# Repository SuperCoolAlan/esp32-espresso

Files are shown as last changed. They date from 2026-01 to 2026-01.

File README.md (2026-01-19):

# ESP32 Espresso Machine Controller

An open-source PID temperature controller for espresso machines, featuring WiFi connectivity and precise temperature control.

## Project Structure

```
esp32-espresso/
├── pid-controller/     # PCB design (atopile)
│   ├── main.ato        # Main circuit definition
│   ├── components/     # Custom component definitions
│   └── build/          # Generated manufacturing files
└── pyproject.toml      # Python dependencies
```

## Hardware

The controller board is designed in [atopile](https://atopile.io) and manufactured via JLCPCB.

### Features

- **ESP32-S3** microcontroller with WiFi/BLE
- **On-board AC-DC converter** (100-240V AC → 5V DC) - direct mains power
- **USB Type-C** for programming/debugging (also provides backup power)
- **MAX31855** K-type thermocouple interface for precise temperature measurement
- **External SSR control** for heater switching (supports 25A panel-mount SSRs)
- **Pressure sensor input** with 5V→3.3V level shifting
- **Status LEDs** for system state indication

See [pid-controller/README.md](pid-controller/README.md) for detailed board documentation.

## Building the PCB

```bash
# Install dependencies
uv sync

# Build the PCB
cd pid-controller
ato build
```

Manufacturing files will be generated in `pid-controller/build/default/`.

## License

See individual component licenses in their respective directories.

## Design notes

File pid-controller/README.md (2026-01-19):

# ESP32-S3 PID Controller for Espresso Machine

A PID temperature controller board designed for the Rancilio Silvia espresso machine, built with [atopile](https://atopile.io).

## TODO

- [ ] **Fuse on AC input** - protects against shorts/overcurrent
- [ ] **MOV/TVS on AC input** - surge protection from mains spikes
- [ ] **TVS diodes on USB D+/D-** - ESD protection (e.g., USBLC6-2)
- [ ] **TVS on thermocouple inputs** - TC wires run outside enclosure
- [ ] **Power LED** - indicates board is powered
- [ ] **Reset button** - useful for development
- [ ] **Mounting holes** - for securing PCB in enclosure
- [ ] **Test points** - on key signals for debugging
- [ ] **Fiducials** - alignment markers for pick and place assembly

## Board Overview

This board provides closed-loop temperature control for an espresso machine boiler using a K-type thermocouple and an external solid-state relay.

### Major Components

| Component | Part Number | Description |
|---|---|---|
| MCU | ESP32-S3-WROOM-1-N8 | WiFi/BLE module, 8MB flash |
| AC-DC Converter | HLK-PM01 | 100-240V AC → 5V DC @ 600mA (3W) |
| Thermocouple IC | MAX31855KASA | K-type thermocouple-to-digital converter |
| Voltage Regulator | AMS1117-3.3 | 3.3V LDO (from 5V) |
| SSR Driver | BC817-40 | NPN transistor for external SSR control |
| Power Diode | SS14 | Schottky diode for USB/AC power OR-ing |

### Connectors / Terminals

| Connector | Pins | Function |
|---|---|---|
| J_AC | 2 | AC mains input (Line, Neutral) |
| J_USB | USB-C | Programming/debugging + backup 5V power |
| J_TC | 2 | K-type thermocouple input (TC+, TC-) |
| J_SSR | 2 | External SSR control output (SSR+, SSR-) |
| J_PRESSURE | 3 | Pressure sensor input (+5V, Signal, GND) |

### Status LEDs

| LED | Color | Function |
|-----|---|---|
| LED_OK | Green | System running / OK |
| LED_HEAT | Orange | Heating element active |
| LED_ERR | Red | Error condition |

All LEDs are active-low (accent driven by GPIO sinking current).

## Pin Assignments

### ESP32-S3 GPIO Usage

| GPIO | Function |
|---|---|
| IO1 | Pressure sensor ADC input |
| IO4 | SSR control output |
| IO5 | Green LED (OK) |
| IO6 | Orange LED (Heating) |
| IO7 | Red LED (Error) |
| IO10 | SPI CS (MAX31855) |
| IO11 | SPI MOSI (unused) |
| IO12 | SPI CLK (MAX31855) |
| IO13 | SPI MISO (MAX31855) |
| IO19 | USB D- |
| IO20 | USB D+ |

## External SSR Wiring

This board outputs a control signal for an external panel-mount SSR (e.g., Fotek SSR-25DA or similar 25A SSR). The external SSR provides better heat dissipation for high-power loads.

```
Board J_SSR          External SSR (25A)         Heater
┌─────────┐          ┌─────────────┐           ┌──────┐
│ Pin 1 ──┼──────────┤ Input +     │           │      │
│ (SSR+)  │          │ (3-32VDC)   │           │      │
│         │          │             ├───────────┤ Load │
│ Pin 2 ──┼──────────┤ Input -     │    AC     │      │
│ (SSR-)  │          │             ├───────────┤      │
└─────────┘          └─────────────┘           └──────┘
```

## Circuit Features

- **AC-DC Power**: On-board HLK-PM01 isolated converter (100-240V AC → 5V DC)
- **USB Type-C**: For programming/debugging, with Schottky diode power OR-ing
- **Dual Power Sources**: USB power works when AC is disconnected (for bench programming)
- **Boot Circuit**: 10k pullup + 1µF RC delay on EN pin for reliable power-on reset
- **Boot Mode**: 10k pullup on GPIO0 for normal SPI flash boot
- **Decoupling**: 100nF + 10µF on 3.3V rail, 10µF + 22µF on LDO
- **Pressure Sensor**: 10k/20k voltage divider (5V → 3.3V) with 100nF filter cap

## Building

Requires [atopile](https://atopile.io) v0.12.4 or later.

```bash
cd pid-controller
ato build
```

Build outputs are placed in `build/default/`.

## BOM / Ordering

All components are available from JLCPCB/LCSC. Run `ato build` to generate the BOM and manufacturing files.

## License

See [LICENSE.txt](LICENSE.txt)

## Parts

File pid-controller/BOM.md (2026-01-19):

# PID Controller BOM - Rancilio Silvia

## ICs

| Qty | Ref | Component | Value | Package | LCSC | DigiKey |
|-----|-----|---|---|---|---|---|
| 1 | U1 | ESP32-S3-WROOM-1-N8 | - | Module | C2913198 | |
| 1 | U2 | MAX31855KASA+T | K-type TC | SOIC-8 | C52028 | |
| 1 | U3 | AMS1117-3.3 | 3.3V LDO | SOT-223 | C6186 | |

## Discrete Semiconductors

| Qty | Ref | Component | Value | Package | LCSC | DigiKey |
|-----|-----|---|---|---|---|---|
| 1 | U4 | AQ10A2-ZT4/32VDC | 10A SSR | SIP-4 | C6507016 | https://www.digikey.com/en/products/detail/panasonic-electric-works/AQ10A2-ZT4-32VDC/3992067 |
| 1 | Q1 | BC817-40 | NPN | SOT-23 | C8589 | |

## Resistors (0603)

| Qty | Ref | Component | Value | Package | LCSC | DigiKey |
|-----|-----|---|---|---|---|---|
| 1 | R1 | R_base | 1k | 0603 | | |
| 1 | R2 | R_ssr | 100 ohm | 0603 | | |
| 1 | R3 | R_div_top | 10k | 0603 | | |
| 1 | R4 | R_div_bot | 15k | 0603 | | |
| 3 | R5-R7 | R_led | 200 ohm | 0603 | | |

## Capacitors (0603)

| Qty | Ref | Component | Value | Package | LCSC | DigiKey |
|-----|-----|---|---|---|---|---|
| 2 | C1-C2 | C_in, C_out | 10uF | 0603 | | |
| 4 | C3-C6 | C_bypass (ESP32) | 100nF | 0603 | | |
| 1 | C7 | C_bypass (MAX31855) | 100nF | 0603 | | |
| 1 | C8 | C_adc | 100nF | 0603 | | |

## LEDs (0603)

| Qty | Ref | Component | Color | Package | LCSC | DigiKey |
|-----|-----|---|---|---|---|---|
| 1 | D1 | LED_OK | Green | 0603 | | |
| 1 | D2 | LED_Heat | Orange | 0603 | | |
| 1 | D3 | LED_Err | Red | 0603 | | |

## Connectors

| Qty | Ref | Component | Description | Package | LCSC | DigiKey |
|-----|-----|---|---|---|---|---|
| 1 | J1 | J_power | 5V Power input | Phoenix 2-pos | | |
| 1 | J2 | J_tc | Thermocouple input | Phoenix 2-pos | | |
| 1 | J3 | J_heater | AC heater output | Phoenix 2-pos | | |
| 1 | J4 | J_pressure | Pressure sensor | Phoenix 3-pos | | |

---

## Notes

- **SSR Cooling**: Dissipates ~7-10W at full load (8.3A). Requires heatsink or chassis mounting with thermal pad.
- **Voltage Divider**: Scales 5V pressure sensor output to 3.3V ADC range (10k/15k = 3.0V max).
- **LEDs**: Active-low (cathode to GPIO). 200 ohm for ~5mA at 3.3V.
- **LCSC IDs**: For JLCPCB assembly. SSR (C6507016) may be out of stock - order from DigiKey.

## Assembly Options

1. **JLCPCB SMT**: Use LCSC IDs for automated assembly (excludes SSR, connectors)
2. **DigiKey + Reflow**: Order all from DigiKey, reflow at home
3. **Hybrid**: JLCPCB for SMD, hand-solder SSR and connectors

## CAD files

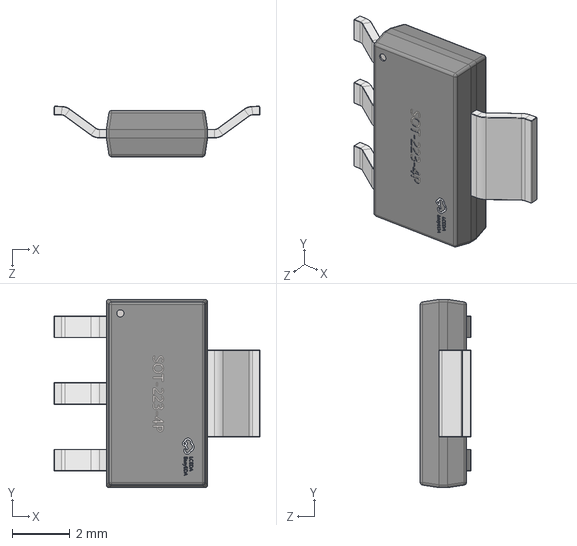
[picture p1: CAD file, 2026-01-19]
pid-controller/parts/Advanced_Monolithic_Systems_AMS1117_3_3/SOT-223-4P_L6.5-W3.5-H1.6-LS7.0-P2.30.step
7.11 x 6.50 x 1.75 mm

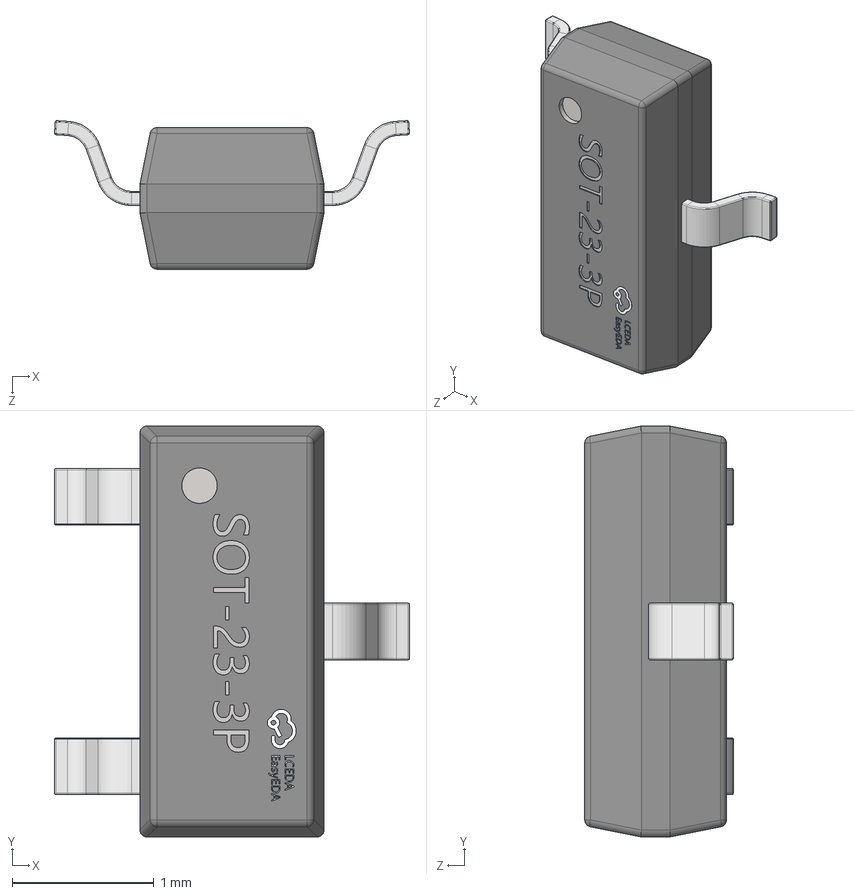
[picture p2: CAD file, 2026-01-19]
pid-controller/parts/Changjiang_Electronics_Tech_BC817_40_RANGE_250_600/SOT-23-3P_L2.9-W1.3-H1.0-LS2.4-P0.95.step
2.51 x 2.90 x 1.05 mm

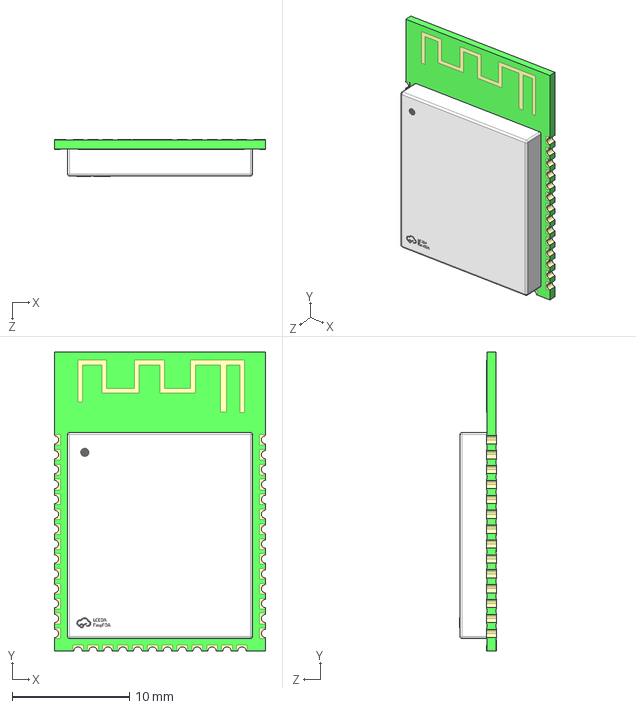
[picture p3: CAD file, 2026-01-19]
pid-controller/parts/Espressif_Systems_ESP32_S3_WROOM_1_N8/WIFIM-SMD_ESP32-S3-WROOM-1-N8.STEP
18.0 x 25.5 x 3.12 mm

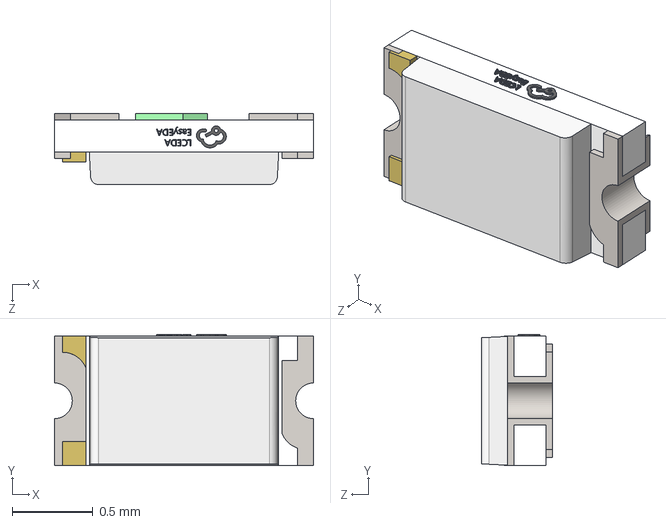
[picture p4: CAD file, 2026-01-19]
pid-controller/parts/Everlight_Elec_19_217_BHC_ZL1M2RY_3T/LED0603-FD_BLUE.step
1.60 x 0.81 x 0.44 mm

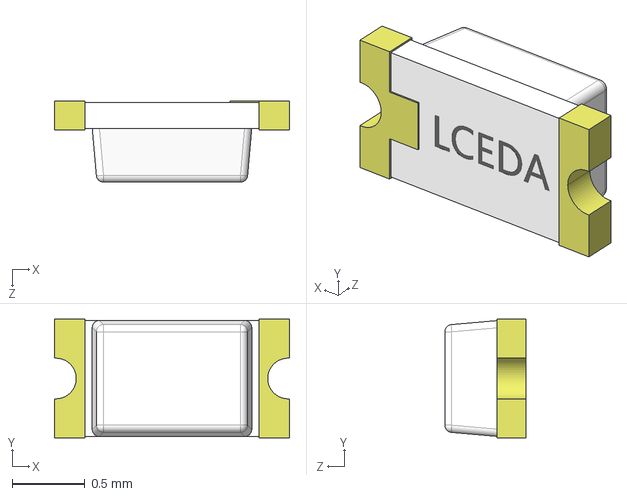
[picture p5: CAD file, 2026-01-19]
pid-controller/parts/Everlight_Elec_19_217_GHC_YR1S2_3T/LED0603-RD-YELLOW.STEP
1.62 x 0.82 x 0.56 mm

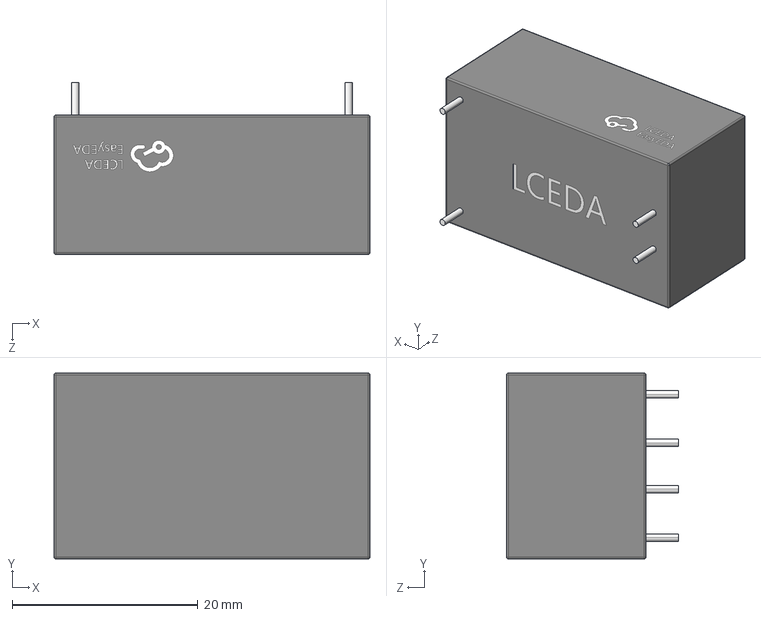
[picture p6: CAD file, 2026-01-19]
pid-controller/parts/HI_LINK_HLK_PM01/PWRM-TH_L34.0-W20.0-H15.0.step
34.0 x 20.0 x 18.5 mm

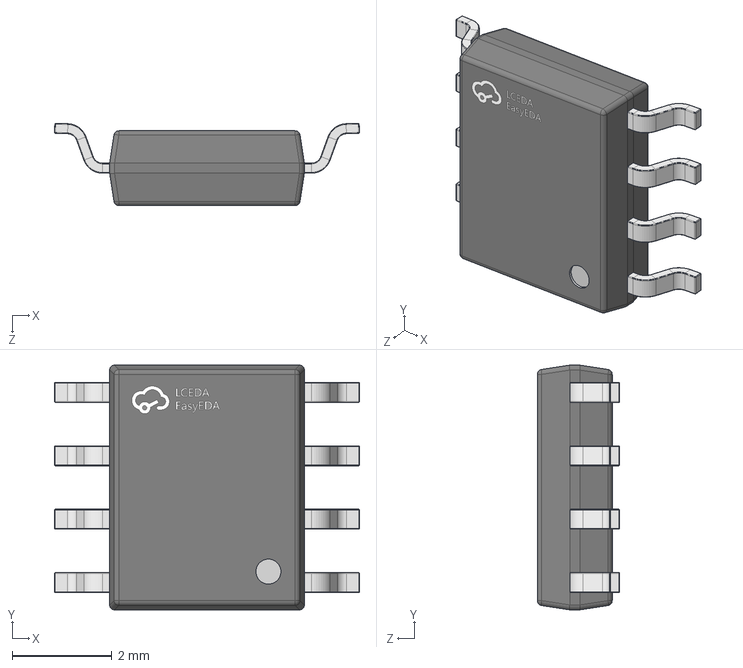
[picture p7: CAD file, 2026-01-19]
pid-controller/parts/Maxim_Integrated_MAX31855KASA_T/SO-8_L4.9-W3.9-H1.5-LS5.9-P1.27.step
6.11 x 4.90 x 1.65 mm

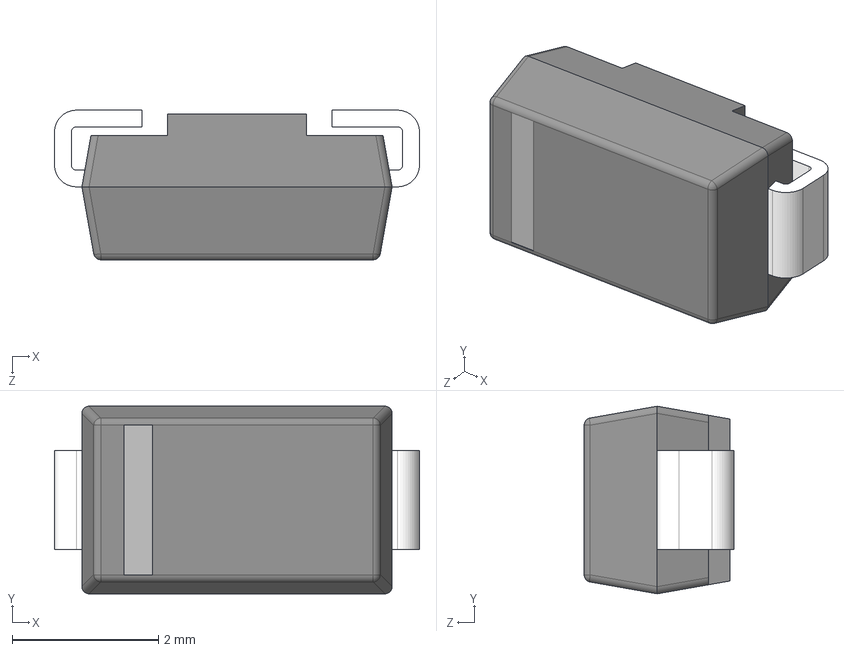
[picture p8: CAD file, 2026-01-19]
pid-controller/parts/MDD_Microdiode_Electronics_SS14/SMA_L4.2-W2.6-LS5.0-RD_1.STEP
5.00 x 2.57 x 2.05 mm

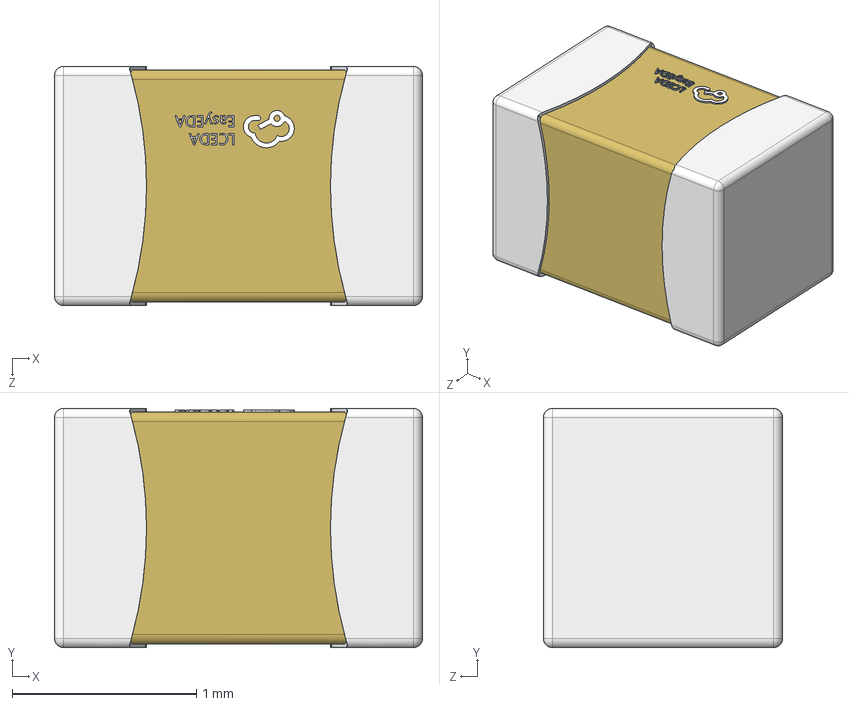
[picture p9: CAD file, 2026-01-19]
pid-controller/parts/Murata_Electronics_GRM21BR60J107ME15L/C0805_L2.0-W1.3-H1.3.step
2.00 x 1.30 x 1.30 mm

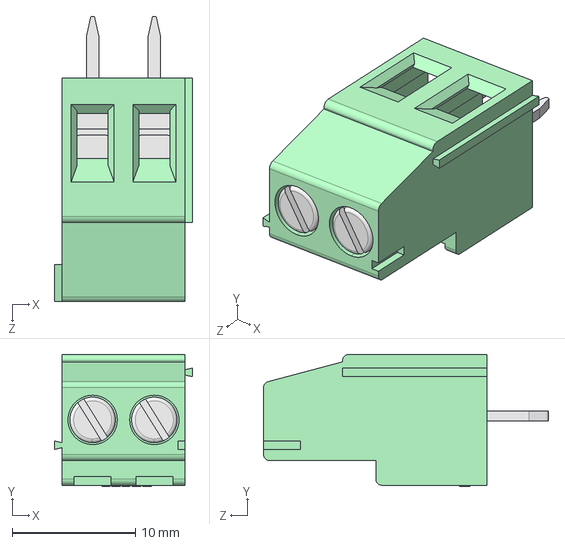
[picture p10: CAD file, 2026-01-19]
pid-controller/parts/Ningbo_Kangnex_Elec_WJ129V_5_0_02P_14_00A/conn-th_2p-p5x00_wj129v-5x00-2p.step
11.2 x 10.7 x 23.1 mm

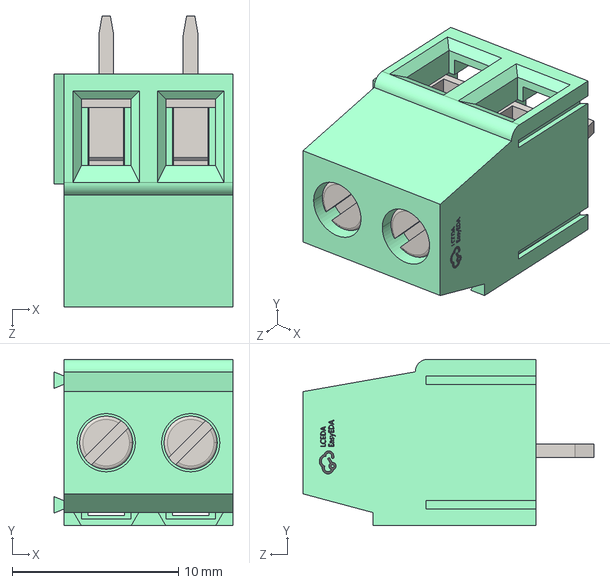
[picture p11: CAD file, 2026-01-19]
pid-controller/parts/Ningbo_Kangnex_Elec_WJ500V_5_08_2P/CONN-TH_2P-P5.00_WJ500V-5.08-2P.step
10.8 x 10.0 x 17.5 mm

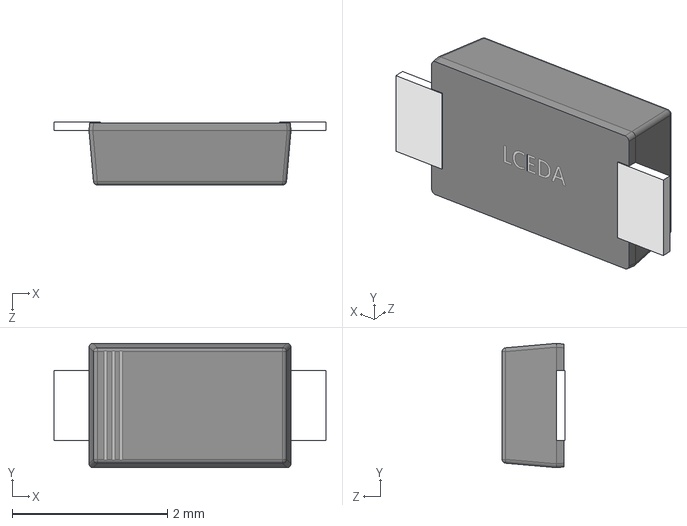
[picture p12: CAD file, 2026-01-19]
pid-controller/parts/ROHM_Semicon_KDZVTR3_9B/SOD-123FL_L2.6-W1.6-LS3.5-RD.STEP
3.50 x 1.60 x 0.81 mm

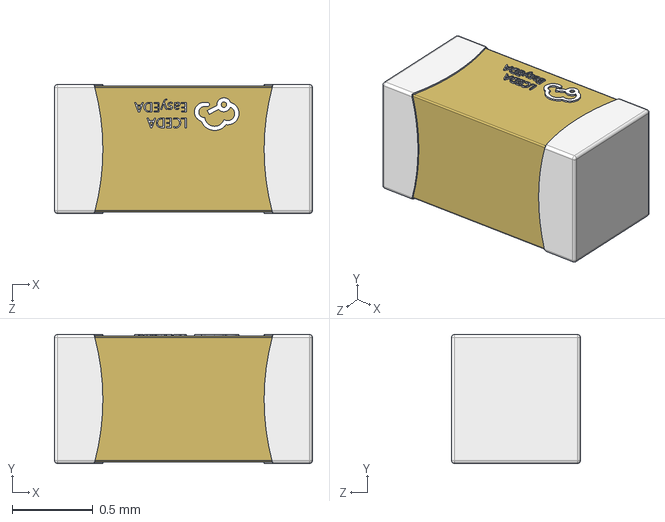
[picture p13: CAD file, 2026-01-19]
pid-controller/parts/Samsung_Electro_Mechanics_CL10A105KB8NNNC/C0603_L1.6-W0.8-H0.8.step
1.60 x 0.8 x 0.8 mm

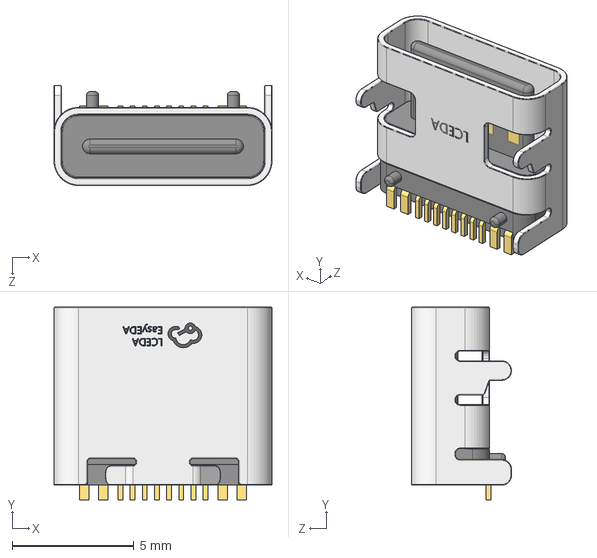
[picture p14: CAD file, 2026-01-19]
pid-controller/parts/SHOU_HAN_TYPE_C16PIN/USB-C-SMD_TYPE-C16PIN.step
8.94 x 7.90 x 4.10 mm

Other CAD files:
pid-controller/parts/UNI_ROYAL_0402WGF5101TCE/R0402_L1.0-W0.5-H0.4.step
pid-controller/parts/UNI_ROYAL_0603WAF1000T5E/R0603.STEP
pid-controller/parts/UNI_ROYAL_0603WAF1001T5E/R0603.STEP
pid-controller/parts/UNI_ROYAL_0603WAF1002T5E/R0603.STEP
pid-controller/parts/UNI_ROYAL_0603WAF1200T5E/R0603.STEP
pid-controller/parts/UNI_ROYAL_0603WAF1500T5E/R0603.STEP
pid-controller/parts/UNI_ROYAL_0603WAF2002T5E/R0603.STEP
pid-controller/parts/XFCN_BH254V_20P/CONN-TH_20P-P2.54_BH254V-20P.STEP
pid-controller/parts/XFCN_PZ254V_11_04P/HDR-TH_4P-P2.54-M-LI-1X4P.step
pid-controller/parts/XFCN_PZ254V_11_06P/HDR-TH_6P-P2.54-M-LI-1X6P.step

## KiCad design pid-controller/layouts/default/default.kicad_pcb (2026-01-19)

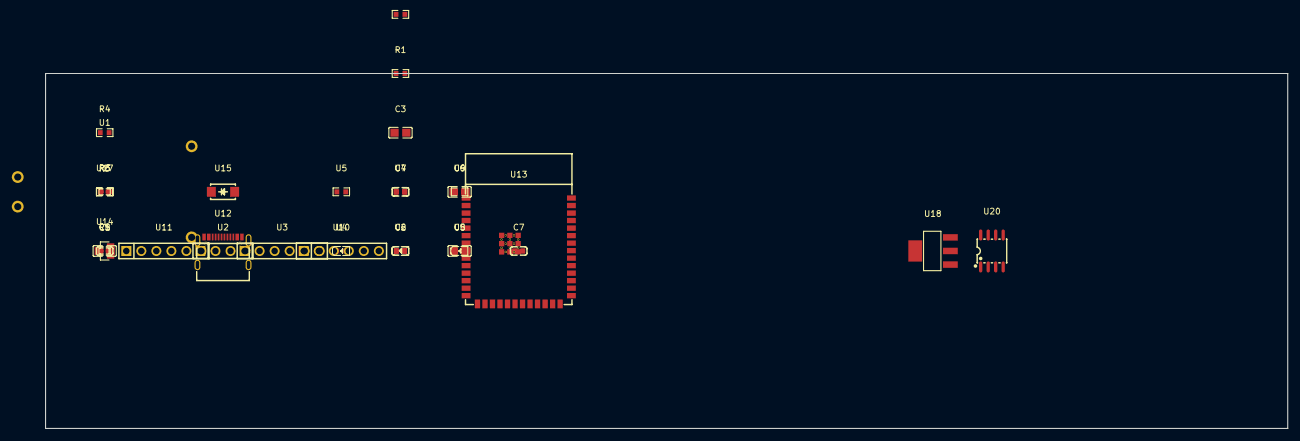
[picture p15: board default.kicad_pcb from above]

Board: 2 copper layers, 210.0 x 60.0 mm, 32 parts (0 on the bottom side), 28 nets, no tracks yet.

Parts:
C1, C4, C7: 100nF ±10% 50V X7R; C0603
C2: 1µF ±10% 50V X5R; C0603
C3, C5: 10µF ±10% 25V X5R; C0805
C6: 22µF ±20% 25V X5R; C0805
C8: 100µF ±20% 6.3V X5R; C0805
R1, R2, R4: 10kΩ ±1% 100mW; R0603
R3: 20kΩ ±1% 100mW; R0603
R5, R6: 5.1kΩ ±1% 62.5mW; R0402
U1: PWRM-TH_HLK-PM01
U2: HDR-TH_4P-P2.54-V-M
U3, U10, U11: HDR-TH_6P-P2.54-V-M
U4, U8: LED0603-RD
U5: 150Ω ±1% 100mW; R0603
U6: LED0603-FD_BLUE
U7: 120Ω ±1% 100mW; R0603
U9: 100Ω ±1% 100mW; R0603
U12: USB-C-SMD_TYPE-C16PIN
U13: WIFIM-SMD_ESP32-S3-WROOM-1-N8
U14: SOT-23-3_L2.9-W1.3-P1.90-LS2.4-BR
U15: SMA_L4.2-W2.6-LS5.0-RD_1
U17: 1kΩ ±1% 100mW; R0603
U18: SOT-223-3_L6.5-W3.4-P2.30-LS7.0-BR
U20: SO-8_L4.9-W3.9-P1.27-LS5.9-BL

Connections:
A5: R5.1, U12.A5
B5: R6.1, U12.B5
GND: C1.2, C2.2, C3.2, C4.2, C5.2, C6.2, C7.2, C8.2, R3.2, R5.2, R6.2, U1.3, U2.3, U12.1, U12.2, U12.3, U12.4, U12.A1B12, U12.B1A12, U13.1, U13.40, U13.41, U14.2, U18.1, U20.1
ac_line: U1.1, U11.1
ac_neutral: U1.2, U11.2
base: U14.1, U17.2
conn-anode: U12.A4B9, U12.B4A9, U15.1
cs: U13.18, U20.6
en: C2.1, R2.2, U13.3
footprint-anode-0: U4.2, U5.2
footprint-anode-1: U6.2, U7.2
footprint-anode-2: U8.2, U9.2
footprint-ctrl-0: U4.1, U13.7
footprint-ctrl-1: U6.1, U13.6
footprint-ctrl-2: U8.1, U13.5
footprint-ctrl-3: U13.4, U17.1
io0: R1.2, U13.27
output: R4.1, U2.2
power-VCC: C3.1, C4.1, C6.1, C7.1, R1.1, R2.1, U5.1, U7.1, U9.1, U13.2, U18.2, U20.4
power_5v-VCC: C5.1, C8.1, U1.4, U2.1, U3.1, U15.2, U18.3
pressure_adc: C1.1, R3.1, R4.2, U13.26
sck: U13.20, U20.5
spi_miso: U13.21, U20.7
ssr_neg: U3.2, U14.3
tc_minus: U10.2, U20.2
tc_plus: U10.1, U20.3
usb_dm: U12.A7, U12.B7, U13.13
usb_dp: U12.A6, U12.B6, U13.14

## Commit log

2026-01-19 Add ESP32-S3 PID controller for Rancilio Silvia espresso machine
    Initial atopile-based PCB design featuring:
    - ESP32-S3-WROOM-1 MCU with EN circuit and boot pullup
    - MAX31855 K-type thermocouple interface (SPI)
    - External SSR driver circuit for panel-mount SSR (Fotek SSR-25DA)
    - Pressure sensor input with 5V->3.3V voltage divider
    - 3 status LEDs (green/orange/red, active-low)
    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
    [C0603_L1.6-W0.8-H0.8.step, C0805_L2.0-W1.3-H1.3.step, CONN-TH_2P-P5.00_WJ500V-5.08-2P.step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]
2026-01-19 Update README with board overview and documentation
    Add comprehensive documentation including:
    - Major components table (ESP32-S3, MAX31855, AMS1117, BC817)
    - Connector pinouts (power, thermocouple, SSR, pressure sensor)
    - Status LED descriptions
    - ESP32 GPIO assignments
    - External SSR wiring diagram
    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
2026-01-19 Add project-level README
    Describe overall project structure, features, and link to
    detailed board documentation in pid-controller/.
2026-01-19 Add AC-DC converter and USB programming header
    - Add HLK-PM01 AC-DC converter (100-240V AC → 5V DC @ 600mA)
    - Add USB 4-pin header with Schottky diode for programming
    - Add AC input connector for mains power
    - Update main.ato to use on-board AC power instead of 5V input
    - USB power OR-ing allows programming without AC connected
    [C0805_L2.0-W1.3-H1.3.step, CONN-TH_20P-P2.54_BH254V-20P.STEP, PWRM-TH_L34.0-W20.0-H15.0.step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]
2026-01-19 Switch to USB Type-C connector for programming
    - Replace 4-pin USB header with USB Type-C (LCSC C393939)
    - Add CC resistors (5.1k) for UFP device mode detection
    - Pin mapping matches LCSC footprint exactly
    - Schottky diode allows USB power when AC is off
    [R0402_L1.0-W0.5-H0.4.step, default.kicad_pcb]
2026-01-19 Update READMEs with AC-DC and USB-C documentation
    - Document HLK-PM01 AC-DC converter in components table
    - Add USB Type-C connector to terminals list
    - Update circuit features with power OR-ing info
    - Update root README with new power features
2026-01-19 Add TODO list for missing best practices
    - AC safety: fuse, MOV/TVS surge protection
    - ESD protection: USB TVS, thermocouple TVS
    - Usability: power LED, reset button
    - Mechanical: mounting holes, test points
